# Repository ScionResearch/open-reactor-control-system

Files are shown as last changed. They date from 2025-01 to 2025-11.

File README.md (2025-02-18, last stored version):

# Open Reactor Control System

A unified control platform for bioreactor systems, featuring a dual microcontroller architecture for robust control and monitoring capabilities.

## Hardware Architecture

The system is built around two microcontrollers:

1. **System Controller (RP2040)**
   - Primary system controller
   - Handles user interface and high-level control
   - Based on the Raspberry Pi RP2040 microcontroller
   - USB connectivity for configuration and monitoring

2. **I/O Controller (SAMD51)**
   - Dedicated I/O processing
   - Real-time sensor monitoring and control
   - Based on the Microchip SAMD51 microcontroller
   - Provides reliable, deterministic I/O handling

## Project Structure

- `orc-sys-mcu/`: System Controller firmware (RP2040)
- `orc-io-mcu/`: I/O Controller firmware (SAMD51)
- `hardware/`: Hardware design files and documentation
  - Schematics
  - Pin assignments
  - PCB design files

## PCB Assembly

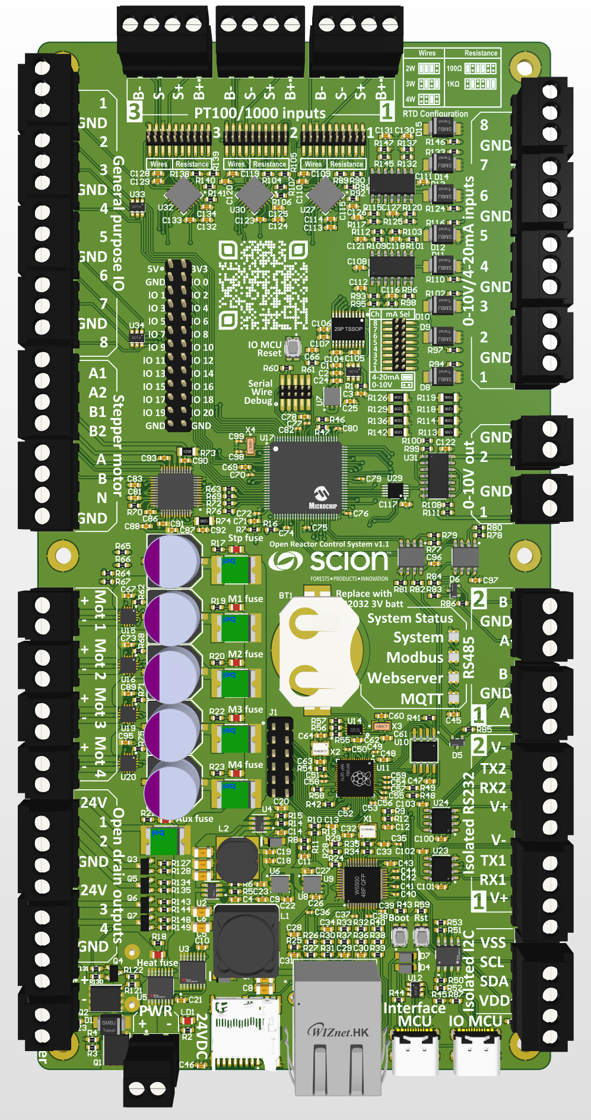
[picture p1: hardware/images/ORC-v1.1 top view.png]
PCB Top View

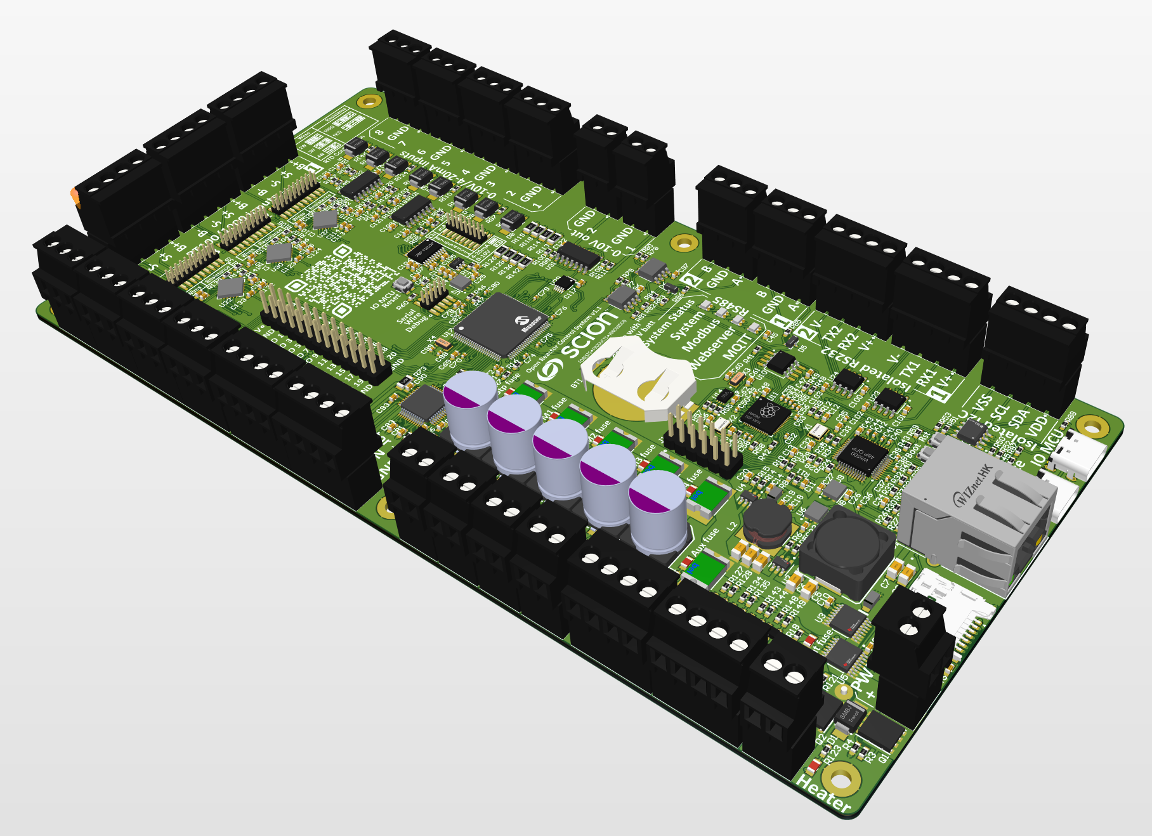
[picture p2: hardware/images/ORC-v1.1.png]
PCB Assembly


## Current Status

This project is currently under active development. The basic hardware and firmware architecture is established, with ongoing work to implement and refine the control and monitoring capabilities.

## Development

This is a PlatformIO-based project. Each microcontroller has its own PlatformIO project configuration and can be built and programmed independently.

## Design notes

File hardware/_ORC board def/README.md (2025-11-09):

# Scion ORC M4 Custom Board Definition

This directory contains the custom PlatformIO board definition for the Scion Open Reactor Controller M4 (ORC-IO-MCU).

## Board Specifications

- **MCU**: ATSAME51N20A (Cortex-M4)
- **Clock Speed**: 120 MHz
- **RAM**: 256 KB
- **Flash**: 1 MB (with bootloader offset)
- **USB VID/PID**: 0x04D8:0xEB60, 0x04D8:0xEB61

## Directory Structure

```
_ORC board def/
├── boards/
│   └── scion_orc_m4.json          # Board definition for PlatformIO
├── variants/
│   └── orc_m4/
│       ├── variant.h               # Pin definitions and mappings
│       ├── variant.cpp             # Pin configuration implementation
│       ├── pins_arduino.h          # Arduino-style pin mapping
│       └── linker_scripts/
│           └── gcc/
│               ├── flash_with_bootloader.ld     # Linker script with bootloader
│               └── flash_without_bootloader.ld  # Linker script without bootloader
└── bootloaders/
    └── orc_m4/
        ├── bootloader-orc_io_m4-v3.16.0-19-g4365018.bin
        └── update-bootloader-orc_io_m4-v3.16.0-19-g4365018.uf2
```

## PlatformIO Integration

### Automatic Setup (Already Configured)

The `orc-io-mcu/platformio.ini` is already configured to use this custom board definition:

```ini
[platformio]
boards_dir = ../hardware/_ORC board def/boards

[env:scion_orc_m4]
platform = atmelsam
board = scion_orc_m4
framework = arduino
board_build.variants_dir = ../hardware/_ORC board def/variants
lib_deps =
    khoih-prog/FlashStorage_SAMD@^1.3.2
```

**No additional setup is required** - PlatformIO will automatically find and use the custom board definition.

### How It Works

1. **`boards_dir`** - Tells PlatformIO where to find custom board JSON files
2. **`board`** - References the board name (matches `scion_orc_m4.json`)
3. **`board_build.variants_dir`** - Points to custom pin definitions and linker scripts

When you run `pio run`, PlatformIO will:
- Load the board configuration from `boards/scion_orc_m4.json`
- Use the variant files from `variants/orc_m4/` for pin mappings
- Apply the correct linker script (`flash_with_bootloader.ld`)
- Configure compiler flags for SAMD51 with FPU support

## Board Configuration Details

The `scion_orc_m4.json` file defines:

- **Build settings**: Cortex-M4 with FPU, SAMD51 core, 120MHz clock
- **Debug support**: J-Link, Atmel-ICE, OpenOCD configurations
- **Upload protocols**: SAM-BA (USB bootloader), J-Link, Atmel-ICE
- **Bootloader offset**: 0x4000 (16KB reserved for UF2 bootloader)

## Bootloader

The board uses a UF2 bootloader based on Adafruit's SAMD bootloader:

- **Version**: v3.16.0-19-g4365018
- **Offset**: 0x4000 (16KB)
- **Protocol**: SAM-BA over USB
- **Features**:
  - USB mass storage device (appears as "ORCM4BOOT")
  - 1200 baud touch to enter bootloader mode
  - Native USB support

### Installing/Updating Bootloader

To update the bootloader:

1. **Via UF2** (if bootloader already present):
   - Double-tap the reset button to enter bootloader mode
   - Drag `update-bootloader-orc_io_m4-v3.16.0-19-g4365018.uf2` to the USB drive

2. **Via J-Link/Atmel-ICE** (for initial programming):
   - Flash `bootloader-orc_io_m4-v3.16.0-19-g4365018.bin` at address 0x00000000

## Pin Definitions

Custom pin mappings are defined in `variants/orc_m4/`:

- Refer to `hardware/SAMD Pin Mux.xlsx` for complete pin assignments
- `variant.h` and `variant.cpp` define Arduino-style pin numbers
- Hardware peripherals (SPI, I2C, UART) are mapped to specific pins

## Troubleshooting

### Board not recognized

If PlatformIO doesn't recognize the board:
```bash
cd orc-io-mcu
pio run --target envdump
```

You should see: `PLATFORM: Atmel SAM > Scion Open Reactor Controller M4`

### Build fails

1. Ensure you're in the `orc-io-mcu` directory
2. Clean and rebuild:
   ```bash
   pio run --target clean
   pio run
   ```

### Upload fails

1. Check USB connection
2. Try entering bootloader mode manually (double-tap reset)
3. Verify the board appears as a USB device:
   ```bash
   ls /dev/ttyACM*
   ```

## Development

### Modifying Pin Definitions

1. Edit `variants/orc_m4/variant.h` and `variant.cpp`
2. Rebuild your project - PlatformIO will use the updated definitions

### Changing Bootloader Settings

1. Edit `boards/scion_orc_m4.json`
2. Modify `upload.offset_address` if changing bootloader size
3. Update linker script accordingly

## References

- [PlatformIO Custom Boards](https://docs.platformio.org/en/latest/platforms/creating_board.html)
- [Atmel SAM Platform](https://docs.platformio.org/en/latest/platforms/atmelsam.html)
- [ATSAME51N20A Datasheet](https://www.microchip.com/en-us/product/ATSAME51N20A)
- [Project Schematics](../Open%20Reactor%20Control%20System%20Schematics%20v1.2.pdf)

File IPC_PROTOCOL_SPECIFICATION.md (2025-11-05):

# Inter-Processor Communication (IPC) Protocol Specification
**Version:** 2.5  
**Date:** 2025-10-27  
**Status:** ✅ Implemented & Operational

---

## 1. OVERVIEW

### 1.1 Purpose
High-speed, robust binary communication protocol between:
- **SAME51N20A** (I/O Controller) - Sensors, actuators, peripherals
- **RP2040** (System Controller) - Network, MQTT, SD, RTC, web UI

### 1.2 Physical Interface
- **Medium:** UART (Serial1)
- **Pins (SAME51):** PIN_MI_TX (52), PIN_MI_RX (53)
- **Pins (RP2040):** PIN_SI_TX (16), PIN_SI_RX (17)
- **Trace Length:** ~80mm PCB trace
- **Baud Rate:** **2,000,000 bps (2 Mbps)** ⚡
  - Tested reliable up to 3 Mbps
  - 2 Mbps selected for robust operation
- **Configuration:** 8N1 (8 data bits, no parity, 1 stop bit)

### 1.3 Design Principles
- ✅ **Lightweight:** 8-byte overhead per packet
- ✅ **Robust:** CRC16-CCITT error detection
- ✅ **Scalable:** Extensible message types, 100-object index
- ✅ **Non-blocking:** Async state machine, TX queue
- ✅ **Fast:** 2 Mbps, minimal latency (<1ms per packet)
- ✅ **Type-safe:** Object type verification on all operations

---

## 2. PACKET STRUCTURE

### 2.1 Binary Frame Format

```
┌──────────┬──────────┬──────────┬──────────┬────────────┬──────────┐
│  START   │  LENGTH  │   MSG    │ PAYLOAD  │    CRC16   │   END    │
│  BYTE    │ (2 bytes)│   TYPE   │ (N bytes)│  (2 bytes) │   BYTE   │
├──────────┼──────────┼──────────┼──────────┼────────────┼──────────┤
│   0x7E   │  uint16  │  uint8   │  0-1024  │   uint16   │   0x7E   │
└──────────┴──────────┴──────────┴──────────┴────────────┴──────────┘

Total overhead: 8 bytes per packet
```

**Field Definitions:**
- **START (0x7E):** Frame delimiter (same for start and end)
- **LENGTH:** Payload size including MSG_TYPE (big-endian uint16)
- **MSG_TYPE:** Message identifier (uint8, see section 3)
- **PAYLOAD:** Variable data (0-1024 bytes max)
- **CRC16:** CRC16-CCITT of LENGTH + MSG_TYPE + PAYLOAD
- **END (0x7E):** Frame delimiter

### 2.2 Byte Stuffing
To prevent frame marker confusion in payload:
- **0x7E** in data → **0x7D 0x5E** (escape + XOR 0x20)
- **0x7D** in data → **0x7D 0x5D** (escape + XOR 0x20)

Applied to: LENGTH, MSG_TYPE, PAYLOAD, CRC fields

### 2.3 CRC16-CCITT
- **Polynomial:** 0x1021
- **Initial Value:** 0xFFFF
- **Coverage:** LENGTH (2) + MSG_TYPE (1) + PAYLOAD (N) bytes
- **Transmission:** Big-endian (MSB first)

---

## 3. MESSAGE TYPES

### 3.1 Message Type Enumeration

```cpp
enum IPC_MsgType : uint8_t {
    // Handshake & Status (0x00-0x0F)
    IPC_MSG_PING            = 0x00,  // Keepalive ping
    IPC_MSG_PONG            = 0x01,  // Ping response ✅ CRITICAL
    IPC_MSG_HELLO           = 0x02,  // Initial handshake
    IPC_MSG_HELLO_ACK       = 0x03,  // Handshake acknowledgment
    IPC_MSG_ERROR           = 0x04,  // Error notification
    
    // Object Index Management (0x10-0x1F)
    IPC_MSG_INDEX_SYNC_REQ  = 0x10,  // Request full index sync
    IPC_MSG_INDEX_SYNC_DATA = 0x11,  // Index sync data packet
    IPC_MSG_INDEX_ADD       = 0x12,  // Add object to index
    IPC_MSG_INDEX_REMOVE    = 0x13,  // Remove object from index
    IPC_MSG_INDEX_UPDATE    = 0x14,  // Update object metadata
    
    // Sensor Data (0x20-0x2F)
    IPC_MSG_SENSOR_READ_REQ      = 0x20,  // Request sensor reading
    IPC_MSG_SENSOR_DATA          = 0x21,  // Sensor data response
    IPC_MSG_SENSOR_STREAM        = 0x22,  // Continuous streaming
    IPC_MSG_SENSOR_BATCH         = 0x23,  // Batch sensor data
    IPC_MSG_SENSOR_BULK_READ_REQ = 0x24,  // ✅ Bulk read request (multiple sensors)
    
    // Control Data (0x30-0x3F)
    IPC_MSG_CONTROL_WRITE   = 0x30,  // Write setpoint/parameter
    IPC_MSG_CONTROL_ACK     = 0x31,  // Write acknowledgment
    IPC_MSG_CONTROL_READ    = 0x32,  // Read control parameters
    IPC_MSG_CONTROL_DATA    = 0x33,  // Control data response
    
    // Device Management (0x40-0x4F)
    IPC_MSG_DEVICE_CREATE   = 0x40,  // Create peripheral device
    IPC_MSG_DEVICE_DELETE   = 0x41,  // Delete peripheral device
    IPC_MSG_DEVICE_CONFIG   = 0x42,  // Configure device
    IPC_MSG_DEVICE_STATUS   = 0x43,  // Device status response
    
    // Fault & Message (0x50-0x5F)
    IPC_MSG_FAULT_NOTIFY    = 0x50,  // Fault notification
    IPC_MSG_MESSAGE_NOTIFY  = 0x51,  // General message
    IPC_MSG_FAULT_CLEAR     = 0x52,  // Clear fault
    
    // Configuration (0x60-0x6F)
    IPC_MSG_CONFIG_READ     = 0x60,  // Read configuration
    IPC_MSG_CONFIG_WRITE    = 0x61,  // Write configuration
    IPC_MSG_CONFIG_DATA     = 0x62,  // Configuration data
    IPC_MSG_CALIBRATE       = 0x63,  // Calibration command
};
```

### 3.2 Message Flow Examples

#### Startup Handshake
```
RP2040 → SAME51: IPC_MSG_HELLO (protocol v1.0.0, firmware v1.0.1)
SAME51 → RP2040: IPC_MSG_HELLO_ACK (firmware v1.0.0, 64 objects max)
RP2040 → SAME51: IPC_MSG_INDEX_SYNC_REQ
SAME51 → RP2040: IPC_MSG_INDEX_SYNC_DATA (entries 0-9)
SAME51 → RP2040: IPC_MSG_INDEX_SYNC_DATA (entries 10-19)
...
```

#### Keepalive (Every 1 Second)
```
SAME51 → RP2040: IPC_MSG_PING
RP2040 → SAME51: IPC_MSG_PONG
```
⚠️ **Connection timeout:** 3 missed PINGs (3 seconds)

---

## 4. PAYLOAD STRUCTURES

### 4.1 Handshake Messages

#### HELLO (0x02)
```cpp
struct IPC_Hello_t {
    uint32_t protocolVersion;  // e.g., 0x00010000 = v1.0.0
    uint32_t firmwareVersion;  // e.g., 0x00010001 = v1.0.1
    char deviceName[32];       // "SAME51-IO-MCU" or "RP2040-ORC-SYS"
} __attribute__((packed));
```

#### HELLO_ACK (0x03)
```cpp
struct IPC_HelloAck_t {
    uint32_t protocolVersion;
    uint32_t firmwareVersion;
    uint16_t maxObjectCount;      // SAME51: 64 (MAX_NUM_OBJECTS)
    uint16_t currentObjectCount;  // Currently registered objects
} __attribute__((packed));
```

### 4.2 Object Index Messages

#### INDEX_SYNC_DATA (0x11)
```cpp
struct IPC_IndexEntry_t {
    uint16_t index;           // 0-79
    uint8_t objectType;       // ObjectType enum
    uint8_t flags;            // Bit 0: valid, Bit 1: fixed
    char name[40];            // Null-terminated name
    char unit[8];             // Unit string (if applicable)
} __attribute__((packed));

struct IPC_IndexSync_t {
    uint16_t packetNum;       // Current packet (0-based)
    uint16_t totalPackets;    // Total packets in sync
    uint8_t entryCount;       // Entries in this packet
    IPC_IndexEntry_t entries[10];  // Up to 10 entries/packet
} __attribute__((packed));
```

### 4.3 Sensor Data Messages

#### SENSOR_DATA (0x21)
```cpp
struct IPC_SensorData_t {
    uint16_t index;          // Object index
    uint8_t objectType;      // Type verification
    uint8_t flags;           // Bit 0: fault, Bit 1: newMessage, Bit 2: running, Bit 3: direction
    float value;             // Primary sensor value
    char unit[8];            // Unit string (for primary value)
    uint32_t timestamp;      // Optional (0 if unused)
    char message[100];       // Optional message
    
    // Multi-value extension (v2.3+)
    uint8_t valueCount;      // Number of additional values (0 = only primary value)
    float additionalValues[4];     // Up to 4 additional values
    char additionalUnits[4][8];    // Units for each additional value
} __attribute__((packed));
```

**Multi-Value Support (v2.3):**
- Complex objects can now transmit multiple related values in a single message
- `valueCount = 0`: Traditional single-value mode (backward compatible)
- `valueCount > 0`: Additional values available in `additionalValues[]` array
- Each additional value has its own unit string in `additionalUnits[]`

**Example Use Cases:**
- **DC Motors:** Primary = power (%), Additional[0] = current (A)
- **Energy Monitors:** Primary = voltage (V), Additional[0] = current (A), Additional[1] = power (W)
- **Hamilton Probes:** Primary = pH/DO, Additional[0] = temperature (°C)
- **Stepper Motor:** Primary = RPM, Additional[0] = current (A)

**Benefits:**
- Single IPC message instead of multiple sensor objects
- Atomically consistent (all values from same measurement cycle)
- More efficient use of object index space
- Reduced IPC traffic

#### SENSOR_BULK_READ_REQ (0x24) ✅ NEW
**Purpose:** Request multiple sensor readings in one operation

```cpp
struct IPC_SensorBulkReadReq_t {
    uint16_t startIndex;     // Starting object index (e.g., 0)
    uint16_t count;          // Number of objects to read (e.g., 21)
} __attribute__((packed));
```

**Response:** Multiple `IPC_MSG_SENSOR_DATA` (0x21) packets sent sequentially

**Example Flow:**
```
RP2040 → SAME51: SENSOR_BULK_READ_REQ (startIndex=0, count=31)
SAME51 → RP2040: SENSOR_DATA (index=0, ADC 1)
SAME51 → RP2040: SENSOR_DATA (index=1, ADC 2)
...
SAME51 → RP2040: SENSOR_DATA (index=20, GPIO 8)
SAME51 → RP2040: SENSOR_DATA (index=21, Digital Output 1)
...
SAME51 → RP2040: SENSOR_DATA (index=30, DC Motor 4)
```

**TX Queue Management:** 
- IO MCU TX queue limited to 8 packets
- Handler actively drains queue by calling `ipc_processTxQueue()` between sends
- Waits for queue space before sending each response (prevents overflow)
- Typical performance: 31 objects read in ~30-40ms

**Benefits:**
- Single 4-byte request vs 31 individual requests (96% reduction)
- Prevents RX buffer overflow on SYS MCU
- Efficient bulk object polling for cache updates
- Used by background polling: 31 objects (sensors + outputs) updated every 1 second
- Provides real-time output status (running state, power, current, etc.)

### 4.4 Control Messages 🚧 IN PROGRESS

#### CONTROL_WRITE (0x30) - Digital Output Control
**Purpose:** Control digital outputs (on/off, PWM duty cycle)

```cpp
struct IPC_DigitalOutputControl_t {
    uint16_t index;          // Output index (21-25)
    uint8_t objectType;      // Type verification (OBJ_T_DIGITAL_OUTPUT)
    uint8_t command;         // Command type (see below)
    bool state;              // Output state (true=on, false=off)
    float pwmDuty;           // PWM duty cycle (0-100%)
    uint8_t reserved[3];     // Padding for alignment
} __attribute__((packed));
```

**Command Types:**
```cpp
enum DigitalOutputCommand : uint8_t {
    DOUT_CMD_SET_STATE = 0x01,   // Set on/off state
    DOUT_CMD_SET_PWM   = 0x02,   // Set PWM duty cycle
    DOUT_CMD_DISABLE   = 0x03,   // Disable output
};
```

#### CONTROL_WRITE (0x30) - Stepper Motor Control
**Purpose:** Control stepper motor parameters and motion

```cpp
struct IPC_StepperControl_t {
    uint16_t index;          // Stepper index (26)
    uint8_t objectType;      // Type verification (OBJ_T_STEPPER_MOTOR)
    uint8_t command;         // Command type (see below)
    float rpm;               // Target RPM
    bool direction;          // true=forward, false=reverse
    bool enable;             // Enable motor
    uint8_t reserved[2];     // Padding
} __attribute__((packed));
```

**Command Types:**
```cpp
enum StepperCommand : uint8_t {
    STEPPER_CMD_SET_RPM   = 0x01,  // Set target RPM
    STEPPER_CMD_SET_DIR   = 0x02,  // Set direction
    STEPPER_CMD_START     = 0x03,  // Start motor
    STEPPER_CMD_STOP      = 0x04,  // Stop motor
    STEPPER_CMD_UPDATE    = 0x05,  // Update RPM while running
};
```

#### CONTROL_WRITE (0x30) - DC Motor Control
**Purpose:** Control DC motor power and direction

```cpp
struct IPC_DCMotorControl_t {
    uint16_t index;          // Motor index (27-30)
    uint8_t objectType;      // Type verification (OBJ_T_BDC_MOTOR)
    uint8_t command;         // Command type (see below)
    float power;             // Power percentage (0-100%)
    bool direction;          // true=forward, false=reverse
    bool enable;             // Enable motor
    uint8_t reserved[2];     // Padding
} __attribute__((packed));
```

**Command Types:**
```cpp
enum DCMotorCommand : uint8_t {
    DCMOTOR_CMD_SET_POWER = 0x01,  // Set power percentage
    DCMOTOR_CMD_SET_DIR   = 0x02,  // Set direction
    DCMOTOR_CMD_START     = 0x03,  // Start motor
    DCMOTOR_CMD_STOP      = 0x04,  // Stop motor
    DCMOTOR_CMD_UPDATE    = 0x05,  // Update power while running
};
```

#### CONTROL_ACK (0x31) - Command Acknowledgment
**Purpose:** Acknowledge control command success/failure

```cpp
struct IPC_ControlAck_t {
    uint16_t index;          // Object index
    uint8_t objectType;      // Object type
    uint8_t command;         // Command that was executed
    bool success;            // true=success, false=failure
    uint8_t errorCode;       // Error code if success=false
    char message[100];       // Status/error message
} __attribute__((packed));
```

**Error Codes:**
```cpp
enum ControlErrorCode : uint8_t {
    CTRL_ERR_NONE           = 0x00,  // No error
    CTRL_ERR_INVALID_INDEX  = 0x01,  // Invalid object index
    CTRL_ERR_TYPE_MISMATCH  = 0x02,  // Object type mismatch
    CTRL_ERR_INVALID_CMD    = 0x03,  // Invalid command
    CTRL_ERR_OUT_OF_RANGE   = 0x04,  // Parameter out of range
    CTRL_ERR_NOT_ENABLED    = 0x05,  // Device not enabled
    CTRL_ERR_DRIVER_FAULT   = 0x06,  // Hardware driver fault
    CTRL_ERR_TIMEOUT        = 0x07,  // Command timeout
};
```

### 4.5 Configuration Messages ✅ IMPLEMENTED

#### CONFIG_ANALOG_INPUT (ADC Configuration)
```cpp
struct IPC_ConfigAnalogInput_t {
    uint8_t index;           // ADC index (0-7)
    char unit[8];            // Unit string (e.g., "mV", "V", "mA")
    float calScale;          // Calibration scale factor
    float calOffset;         // Calibration offset
} __attribute__((packed));
```

#### CONFIG_RTD (Temperature Sensor Configuration)
```cpp
struct IPC_ConfigRTD_t {
    uint8_t index;           // RTD index (10-12)
    char unit[8];            // Unit string (e.g., "C", "degC")
    uint8_t sensorType;      // 0=PT100, 1=PT1000
    uint8_t wireMode;        // 2=2-wire, 3=3-wire, 4=4-wire
    float calScale;          // Calibration scale factor
    float calOffset;         // Calibration offset
} __attribute__((packed));
```

**Configuration Flow:**
```
RP2040 → SAME51: CONFIG_ANALOG_INPUT (index=0, unit="V", scale=1.0, offset=0.0)
SAME51: Updates ADC configuration in real-time
```

---

## 5. OBJECT INDEX SYSTEM

### 5.1 Index Organization (80 Objects Total)

The object index provides a unified addressing scheme for all sensors, actuators, and control loops accessible via IPC.

**Fixed Indices (0-59):** Onboard SAME51 hardware & control objects

#### **Analog I/O (0-9)**
- **0-7:** Analog Inputs (ADC channels 1-8) - MCP3464
- **8-9:** Analog Outputs (DAC channels 1-2) - MCP48FEB

#### **Temperature Sensors (10-12)**
- **10-12:** RTD Temperature Sensors (PT100/PT1000 1-3) - MAX31865

#### **Digital I/O (13-20)**
- **13-20:** Digital GPIO (8 channels) - General purpose I/O

#### **Digital Outputs (21-25)**
- **21-24:** Digital Outputs (4 channels) - Open-drain, PWM capable
- **25:** Heater Output (1 channel) - High current, 1Hz PWM

#### **Motion Control (26-30)**
- **26:** Stepper Motor - TMC5130 driver
- **27-30:** DC Motors (4 channels) - DRV8235 drivers

#### **Energy Monitoring (31-32)**
- **31:** Main Power Monitor - INA260 sensor 1 (voltage V, current A, power W)
- **32:** Heater Power Monitor - INA260 sensor 2 (voltage V, current A, power W)

#### **Communication Ports (33-36)**
- **33:** Modbus Port 1 (RS-232) - Serial2
- **34:** Modbus Port 2 (RS-232) - Serial3
- **35:** Modbus Port 3 (RS-485) - Serial4
- **36:** Modbus Port 4 (RS-485) - Serial5

#### **Onboard Device Feedback (37-39)** 🚧 Reserved
- **37-39:** Reserved for additional onboard device status/feedback

#### **Controller Objects (40-49)** **WIP**
- **40-42:** Temperature Control (3 loops) - PID controllers
- **43:** pH Control - Dosing control
- **44-47:** Feed/waste Control - pumps
- **48:** Dissolved Oxygen Control - Gas mixing + stirrer
- **49:** Reserved

**Device Control Objects (50-69):** Peripheral device control
- Control interface for dynamic devices (setpoints, commands, status)
- Each device gets one control object (MFC setpoint, pump speed, etc.)
- Linked to sensor objects via `startSensorIndex` field
- **20 slots available** for device control

**Device Sensor Objects (70-99):** User-created peripheral sensors
- Sensor readings from dynamic devices (pH, DO, OD, flow, pressure, etc.)
- User-created via `IPC_MSG_DEVICE_CREATE`
- Assigned sequentially starting at 70, recycled on deletion
- Each device can have 1-4 sensors (e.g., MFC: flow + pressure)
- **30 slots available** for device sensors

### 5.2 Object Type Mapping

Each index has an associated `ObjectType` from the enum:

```cpp
// Sensors
OBJ_T_ANALOG_INPUT              // Indices 0-7
OBJ_T_ANALOG_OUTPUT             // Indices 8-9
OBJ_T_TEMPERATURE_SENSOR        // Indices 10-12, 60+
OBJ_T_DIGITAL_INPUT             // Indices 13-20
OBJ_T_DIGITAL_OUTPUT            // Indices 21-25
OBJ_T_ENERGY_SENSOR             // Indices 31-32 (multi-value: V, A, W)
OBJ_T_VOLTAGE_SENSOR            // Reserved for future use
OBJ_T_CURRENT_SENSOR            // Reserved for future use
OBJ_T_POWER_SENSOR              // Reserved for future use

// Motion
OBJ_T_STEPPER_MOTOR             // Index 26
OBJ_T_BDC_MOTOR                 // Indices 27-30

// Communication
OBJ_T_SERIAL_RS232_PORT         // Indices 33-34
OBJ_T_SERIAL_RS485_PORT         // Indices 35-36

// Controllers (40-49) - Future
OBJ_T_TEMPERATURE_CONTROL       // Indices 40-42
OBJ_T_PH_CONTROL                // Index 43
OBJ_T_DISSOLVED_OXYGEN_CONTROL  // Index 44
OBJ_T_OPTICAL_DENSITY_CONTROL   // Index 45
OBJ_T_GAS_FLOW_CONTROL          // Indices 46-47
OBJ_T_PUMP_CONTROL              // Index 48
OBJ_T_FEED_WASTE_CONTROL        // Index 49

// Device Controls (50-69) - ✅ Active
OBJ_T_DEVICE_CONTROL            // Control/status for peripheral devices

// Device Sensors (70-99) - ✅ Active
OBJ_T_PH_SENSOR                 // Indices 70+ (dynamic)
OBJ_T_DISSOLVED_OXYGEN_SENSOR   // Indices 70+ (dynamic)
OBJ_T_OPTICAL_DENSITY_SENSOR    // Indices 70+ (dynamic)
OBJ_T_FLOW_SENSOR               // Indices 70+ (dynamic)
OBJ_T_PRESSURE_SENSOR           // Indices 70+ (dynamic)
OBJ_T_TEMPERATURE_SENSOR        // Indices 10-12, 70+ (dynamic)
```

### 5.3 Unit Strings

Standard unit strings for sensor data:

| Object Type | Primary Unit | Notes |
|---|---|---|
| Analog Input | `mV` | Millivolts (configurable) |
| Analog Output | `mV` | Millivolts (0-10240 mV) |
| Temperature | `°C` | Celsius (configurable to °F/K) |
| Digital I/O | ` ` | Empty (boolean state) |
| Digital Output | ` ` | Empty (boolean state) |
| Energy Monitor | `V` | Primary: Volts, Additional: A, W |
| Stepper Motor | `rpm` | Revolutions per minute |
| DC Motor | `%` | Power percentage |
| Modbus Port | ` ` | Empty (status/config) |
| pH Sensor | `pH` | pH units (0-14) |
| DO Sensor | `mg/L` or `%` | Dissolved oxygen |
| OD Sensor | `OD` or `AU` | Optical density |
| Flow Sensor | `SLPM` | Standard liters per minute |
| Pressure Sensor | `kPa` or `bar` | Pressure units |

### 5.4 Type Safety
Every command includes `objectType` field:
- Prevents wrong commands to wrong device types
- Mismatch → `IPC_MSG_ERROR` with code `IPC_ERR_TYPE_MISMATCH`
- Validated on both SAME51 and RP2040 sides

### 5.5 Dual-Index Device Model ✅ **NEW v2.5**

Peripheral devices (MFCs, pH probes, pumps) use a **dual-index architecture** separating control from sensors:

#### **Control Object (50-69)**
- **Purpose:** Device setpoints, commands, status
- **One per device:** Single control point for the device
- **Contains:**
  - `setpoint` - Target value (flow rate, pH, etc.)
  - `actualValue` - Feedback from primary sensor
  - `connected` - Modbus/I2C connection status
  - `fault` - Fault condition flag
  - `message` - Status/error messages
  - `startSensorIndex` - Link to sensor objects (70-99)
  - `sensorCount` - Number of associated sensors

#### **Sensor Objects (70-99)**
- **Purpose:** Real-time sensor readings
- **1-4 per device:** Flow, pressure, temperature, etc.
- **Polled continuously:** Included in bulk read (indices 0-99)
- **Standard sensor format:** Value, unit, type, fault flags

#### **Example: Alicat MFC**
```
Index 50: Device Control
  - Setpoint: 100.0 SLPM
  - Actual: 99.8 SLPM (from sensor 70)
  - Connected: true
  - Fault: false
  
Index 70: Flow Sensor (OBJ_T_FLOW_SENSOR)
  - Value: 99.8
  - Unit: "SLPM"
  - Type: FLOW_SENSOR
  
Index 71: Pressure Sensor (OBJ_T_PRESSURE_SENSOR)
  - Value: 25.3
  - Unit: "PSI"
  - Type: PRESSURE_SENSOR
```

#### **Benefits:**
- ✅ **Clean separation:** Control (write) vs sensors (read)
- ✅ **Efficient polling:** Sensors in bulk read, control on-demand
- ✅ **Scalable:** 20 devices with up to 30 total sensors
- ✅ **Consistent API:** Control via `/api/device/{index}`, sensors via `/api/inputs`

---

## 6. DRIVER ARCHITECTURE

### 6.1 SAME51 Implementation

**Files:**
- `src/drivers/ipc/drv_ipc.h` - Driver structure and API
- `src/drivers/ipc/drv_ipc.cpp` - State machine, TX/RX
- `src/drivers/ipc/ipc_protocol.h` - Protocol definitions
- `src/drivers/ipc/ipc_handlers.cpp` - Message handlers

**State Machine:**
```
IDLE → Check for RX bytes, process TX queue
  ↓ (START byte detected)
RECEIVING → Accumulate bytes, unstuff, detect END
  ↓ (END byte detected)
PROCESSING → Validate CRC, dispatch to handler
  ↓
IDLE (or ERROR on failure)
```

**Key Functions:**
```cpp
bool ipc_init(void);
void ipc_update(void);  // Non-blocking, called @ 5ms
bool ipc_sendPacket(uint8_t msgType, const uint8_t *payload, uint16_t len);
bool ipc_sendPing(void);
bool ipc_sendPong(void);
bool ipc_sendHello(void);
bool ipc_isConnected(void);
```

### 6.2 RP2040 Implementation

**Files:**
- `lib/IPCprotocol/IPCProtocol.h` - Protocol class
- `lib/IPCprotocol/IPCProtocol.cpp` - Implementation
- `lib/IPCprotocol/IPCDataStructs.h` - Message structures
- `src/utils/ipcManager.cpp` - Integration layer

**Key Functions:**
```cpp
void begin(uint32_t baudRate = 2000000);
void update(void);  // Non-blocking
bool sendPacket(uint8_t messageType, const uint8_t *payload, uint16_t length);
bool sendPing(void);
bool sendHello(uint32_t protocol, uint32_t firmware, const char* name);
void registerHandler(uint8_t messageType, MessageCallback callback);
```

---

## 7. PERFORMANCE CHARACTERISTICS

### 7.1 Timing @ 2 Mbps
- **Bit time:** 0.5 µs
- **Byte time:** 5 µs (8 data + start + stop bits)
- **100-byte packet:** ~0.5 ms transmission
- **1024-byte packet:** ~5.1 ms transmission

### 7.2 CPU Usage
- **SAME51 IPC task (5ms):** <0.5% CPU
- **RP2040 IPC update:** <0.5% CPU
- **Packet processing:** 50-100 µs per packet

### 7.3 Throughput
- **Theoretical max:** ~200 KB/s (2 Mbps / 10 bits per byte)
- **Practical max:** ~150 KB/s (accounting for overhead)
- **Typical load:** <10 KB/s (sensor data + control)

---

## 8. ERROR HANDLING

### 8.1 Error Codes
```cpp
enum IPC_ErrorCode : uint8_t {
    IPC_ERR_CRC_FAIL       = 0x01,  // CRC validation failed
    IPC_ERR_INVALID_MSG    = 0x02,  // Unknown message type
    IPC_ERR_BUFFER_FULL    = 0x03,  // RX buffer overflow
    IPC_ERR_TIMEOUT        = 0x04,  // Packet timeout
    IPC_ERR_TYPE_MISMATCH  = 0x05,  // Object type mismatch
    IPC_ERR_INDEX_INVALID  = 0x06,  // Invalid object index
    IPC_ERR_QUEUE_FULL     = 0x07,  // TX queue full
    IPC_ERR_NOT_IMPLEMENTED= 0x08,  // Feature not implemented
    IPC_ERR_PARSE_FAIL     = 0x09,  // Payload parse error
};
```

### 8.2 Recovery Strategies
- **CRC error:** Discard packet, log error, continue
- **Buffer overflow:** Clear buffer, resync
- **Connection timeout:** Clear connected flag, await reconnect
- **Type mismatch:** Send error response, reject command

### 8.3 Keepalive System
- SAME51 sends PING every 1000 ms (`IPC_KEEPALIVE_MS`)
- RP2040 responds with PONG
- **Both sides** update `lastActivity` on:
  - Any successful RX packet
  - Any successful TX packet
- Connection timeout: 3000 ms (3 x keepalive interval)
- **Critical:** PONG handler must be implemented on both sides

---

## 9. IMPLEMENTATION STATUS

### 9.1 ✅ Completed Features
- [x] Binary packet framing with byte stuffing
- [x] CRC16-CCITT validation
- [x] State machine RX/TX processing
- [x] TX queue (8 packets deep) with active draining
- [x] PING/PONG keepalive with timeout
- [x] HELLO handshake with version checking
- [x] Message handler registration
- [x] Error detection and reporting
- [x] Non-blocking operation
- [x] 2 Mbps reliable communication
- [x] **Bulk sensor read (SENSOR_BULK_READ_REQ)**
- [x] **Background sensor polling (1 Hz cache updates)**
- [x] **Object cache system on SYS MCU**

### 9.2 🚧 In Progress
- [x] **Output control commands (CONTROL_WRITE, CONTROL_ACK)**
  - [x] Digital outputs (on/off, PWM)
  - [x] Stepper motor (RPM, direction, start/stop)
  - [x] DC motors (power, direction, start/stop)
- [x] **Extend bulk read to include outputs (indices 0-30)**
  - [x] Updated polling from 21 to 31 objects
  - [x] Increased UART FIFO buffer to 8192 bytes
- [ ] **Output configuration persistence on SYS MCU**
- [ ] **Output control command senders on SYS MCU**
- [ ] **Web API endpoints for output control**
- [ ] Object index synchronization (partial - fixed objects working)
- [ ] Device management (create/delete)
- [ ] Calibration protocol

### 9.3 📋 Planned Features
- [ ] Sensor batch messages (multiple sensors per packet)
- [ ] Automatic reconnection with state rebuild
- [ ] REST API for device management
- [ ] MQTT integration for sensor & output data
- [ ] Control loop objects (PID, sequencers)

---

## 10. TESTING & VALIDATION

### 10.1 Protocol Tests
- ✅ PING/PONG exchange
- ✅ HELLO handshake
- ✅ CRC validation (intentional corruption)
- ✅ Byte stuffing (0x7E, 0x7D in payload)
- ✅ Connection timeout detection
- ✅ TX/RX packet counting
- ✅ Baud rate up to 3 Mbps

### 10.2 Test Commands (RP2040 Terminal)
```
ping        - Send PING, wait for PONG
hello       - Send HELLO, initiate handshake
ipc-stats   - Display TX/RX counters, errors
```

---

## 11. CONFIGURATION

### 11.1 Compile-Time Configuration

**SAME51** (`ipc_protocol.h`):
```cpp
#define IPC_PROTOCOL_VERSION    0x00010000  // v1.0.0
#define IPC_TX_QUEUE_SIZE       8           // TX queue depth
#define IPC_KEEPALIVE_MS        1000        // Keepalive interval
#define IPC_DEBUG_ENABLED       0           // Debug output (0=off, 1=on)
#define MAX_NUM_OBJECTS         64          // Max object index
```

**RP2040** (`IPCDataStructs.h`):
```cpp
#define IPC_PROTOCOL_VERSION    0x00010000
#define IPC_TX_QUEUE_SIZE       8
#define IPC_MAX_PAYLOAD_SIZE    1024
#define IPC_MAX_HANDLERS        32
#define IPC_DEBUG_ENABLED       0
```

### 11.2 Baud Rate Configuration

**SAME51** (`drv_ipc.cpp`):
```cpp
ipcDriver.uart->begin(2000000);  // 2 Mbps
```

**RP2040** (`ipcManager.cpp`):
```cpp
ipc.begin(2000000);  // 2 Mbps
```

---

## 12. FUTURE ENHANCEMENTS

### 12.1 Protocol Extensions
- **Message priorities:** Separate queues for critical vs normal
- **Flow control:** Handshake to prevent overflow
- **Compression:** Optional payload compression for large data
- **Encryption:** Optional AES for sensitive data

### 12.2 Feature Additions
- **Streaming mode:** Continuous sensor data without requests
- **Batch operations:** Multiple commands in single packet
- **Firmware updates:** OTA update protocol over IPC
- **Diagnostics:** Built-in protocol analyzer/sniffer

---

## 13. TROUBLESHOOTING

### 13.1 Common Issues

**No communication:**
- Check UART pins (TX/RX crossed between MCUs)
- Verify baud rate matches (2 Mbps on both sides)
- Check ground connection
- Verify Serial1 on correct pins

**Connection timeout:**
- Check PONG handler is registered on both sides
- Verify keepalive is enabled (not disabled for debugging)
- Check `lastActivity` updates on RX/TX

**CRC errors:**
- Check for noise on UART lines
- Verify CRC polynomial matches (0x1021)
- Check byte stuffing implementation
- Try lower baud rate

**Missing messages:**
- Check TX queue size (may be full)
- Verify handler is registered for message type
- Check message type value matches enum
- Enable debug output (`IPC_DEBUG_ENABLED = 1`)

---

## 14. REFERENCES

### 14.1 Related Documents
- `HELLO_HANDSHAKE_IMPLEMENTED.md` - Handshake implementation guide
- `IPC_CLEANUP_COMPLETE.md` - Debug output cleanup
- `PROJECT_OVERVIEW.md` - System architecture

### 14.2 Standards
- **CRC16-CCITT:** ITU-T Recommendation V.41
- **UART:** RS-232 compatible (8N1)

---

**Document Version:** 2.4  
**Protocol Version:** v1.0.0  
**Last Updated:** 2025-10-25  
**Status:** ✅ Operational at 2 Mbps with multi-value sensor data + output control  
**Maintainer:** Open Reactor Control System Team

**Recent Updates (v2.4):**
- Consolidated power sensors from 6 objects to 2 energy monitors (indices 31-32)
- Added `OBJ_T_ENERGY_SENSOR` type with multi-value support (voltage, current, power)
- Shifted COM ports from indices 37-40 to 33-36
- Reserved indices 37-40 for future expansion
- Deprecated individual voltage/current/power sensor types (kept for future use)

**Previous Updates (v2.3):**
- Added multi-value sensor data extension to `IPC_SensorData_t`
- Implemented `valueCount`, `additionalValues[]`, and `additionalUnits[]` fields
- DC motors now transmit power (%) + current (A) in single message
- Backward compatible with single-value objects
- Fixed DRV8235 library bug (static buffer sharing across motor instances)

**Previous Updates (v2.2):**
- Added CONTROL_WRITE (0x30) message structures for outputs
- Added CONTROL_ACK (0x31) acknowledgment structure
- Defined control commands for digital outputs, stepper motor, DC motors
- Added error codes for control command failures
- Updated implementation status for output control feature

**Previous Updates (v2.1):**
- Added SENSOR_BULK_READ_REQ message type (0x24)
- Implemented TX queue draining to handle bulk responses
- Added background sensor polling architecture
- Documented object cache system on SYS MCU

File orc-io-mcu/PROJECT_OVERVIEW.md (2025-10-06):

# Open Reactor Control System - IO MCU
## Project Overview & Architecture Documentation

**Last Updated:** 2025-10-05 16:35

**Recent Changes:**
- **NEW:** Designed comprehensive IPC (Inter-Processor Communication) protocol for SAME51↔RP2040 communication
- Reorganized drivers into `onboard/` and `peripheral/` subdirectories
- Converted peripheral drivers to class-based architecture for multiple instance support
- Added Hamilton Arc common definitions with unit code lookup table (32 unit types)
- Implemented automatic unit reading for Hamilton Arc sensors
- Added HamiltonArcDO driver for dissolved oxygen sensors
- Added HamiltonArcOD driver for optical density sensors
- Expanded sensor unit fields from 5 to 8 characters to accommodate longer unit names

## 1. PROJECT PURPOSE

This is the firmware for the IO MCU (Input/Output Microcontroller Unit) of an Open Reactor Control System (ORC). It's designed to interface with and manage various sensors, outputs, and communication protocols for a bioreactor or similar laboratory equipment.

## 2. HARDWARE PLATFORM

- **MCU:** ATSAME51N20A (ARM Cortex-M4)
  - Custom board: `scion_orc_m4`
  - 120MHz clock speed
  - Framework: Arduino for SAMD
- **Platform:** atmelsam (PlatformIO)
- **Key External Library:** FlashStorage_SAMD@^1.3.2 for EEPROM emulation

## 3. SYSTEM ARCHITECTURE

### 3.1 Core Design Pattern
The system follows a **driver-based, object-oriented architecture** with:
- Centralized initialization in `sys_init.h/cpp`
- Modular drivers for each hardware peripheral
- Task-based scheduling for periodic operations
- Object index system for dynamic sensor/output management
- Calibration support for analog I/O

### 3.2 File Structure
```
orc-io-mcu/
├── lib/                         # Custom libraries
│   ├── Scheduler/              # Custom task scheduler with CPU monitoring
│   ├── modbus-rtu-master/      # Custom non-blocking Modbus RTU master
│   ├── MCP3464/                # 8-channel ADC driver
│   ├── MCP48FEB/               # 2-channel DAC driver
│   ├── MAX31865/               # RTD temperature sensor driver
│   ├── TMC5130/                # Stepper motor driver
│   ├── DRV8235/                # DC motor driver
│   └── INA260/                 # Power sensor driver
├── src/
│   ├── drivers/                # Hardware abstraction drivers
│   │   ├── objects.h/cpp      # Object type definitions & index
│   │   ├── onboard/           # Fixed onboard device drivers
│   │   │   ├── drv_adc.*          # Analog input driver (8 channels)
│   │   │   ├── drv_dac.*          # Analog output driver (2 channels)
│   │   │   ├── drv_rtd.*          # RTD temperature sensors (3x MAX31865)
│   │   │   ├── drv_gpio.*         # GPIO (8 main + 15 expansion)
│   │   │   ├── drv_output.*       # Digital outputs (4 + 1 heater)
│   │   │   ├── drv_modbus.*       # Modbus base driver (4 ports)
│   │   │   ├── drv_stepper.*      # TMC5130 stepper driver
│   │   │   ├── drv_bdc_motor.*    # DRV8235 motor driver (4x)
│   │   │   └── drv_pwr_sensor.*   # INA260 power sensors (2x)
│   │   ├── peripheral/        # External device class-based drivers
│   │   │   ├── drv_modbus_hamilton_arc_common.h  # Hamilton Arc common definitions
│   │   │   ├── drv_modbus_hamilton_ph.*          # Hamilton pH probe (class)
│   │   │   ├── drv_modbus_hamilton_arc_do.*      # Hamilton Arc DO sensor (class)
│   │   │   ├── drv_modbus_hamilton_arc_od.*      # Hamilton Arc OD sensor (class)
│   │   │   └── drv_modbus_alicat_mfc.*           # Alicat MFC (class)
│   │   └── ipc/               # Inter-processor communication
│   │       ├── ipc_protocol.h     # Protocol definitions & structs
│   │       ├── drv_ipc.h          # IPC driver header
│   │       ├── drv_ipc.cpp        # Core driver implementation
│   │       └── ipc_handlers.cpp   # Message handler implementations
│   ├── hardware/
│   │   └── pins.h             # Pin definitions (77 pins defined)
│   ├── tasks/
│   │   └── taskManager.*      # Task instances and scheduler
│   ├── utility/
│   │   └── calibrate.*        # Calibration data management
│   ├── sys_init.h             # System-wide includes
│   └── main.cpp               # Main program
├── IPC_PROTOCOL_PLAN.md       # IPC protocol specification
└── platformio.ini             # Build configuration
```

## 4. OBJECT SYSTEM

### 4.1 Object Types (40+ possible objects)
Defined in `objects.h`, the system supports heterogeneous objects via tagged unions:

**Sensors:**
- AnalogInput_t (8x) - Voltage/current inputs
- DigitalIO_t (8 + 15 expansion)
- TemperatureSensor_t (3x RTD)
- PhSensor_t, DissolvedOxygenSensor_t, OpticalDensitySensor_t
- FlowSensor_t, PressureSensor_t
- PowerSensor_t (2x INA260)

**Outputs:**
- AnalogOutput_t (2x DAC)
- DigitalOutput_t (4 + 1 heater with PWM support)

**Actuators:**
- StepperDevice_t (1x TMC5130)
- MotorDevice_t (4x DRV8235)

**Control Objects:**
- TemperatureControl_t, PhControl_t, DissolvedOxygenControl_t
- gasFlowControl_t, stirrerControl_t, pumpControl_t
- feedControl_t, wasteControl_t

### 4.2 Object Index System
- Global array: `objIndex[MAX_NUM_OBJECTS]` (80 max)
- Each entry contains: type tag, void pointer, name string, valid flag
- Allows dynamic runtime enumeration of all system objects
- Used for communication with main control MCU

### 4.3 Calibration System
- Each analog I/O has a `Calibrate_t` object with scale/offset
- 20-entry calibration table stored in emulated EEPROM (FlashStorage_SAMD)
- Two-point calibration support: `calibrate_calc(expected_1, expected_2, actual_1, actual_2)`
- Version control to force re-initialization when structure changes

## 5. TASK SCHEDULING SYSTEM

### 5.1 Custom Scheduler Library
Located in `lib/Scheduler/`, provides:
- **Non-blocking execution** with millisecond precision
- **Priority support** (high-priority tasks run first)
- **Repeat/one-shot modes**
- **CPU usage tracking** per task (10-second rolling window)
- **Performance statistics** (min/max/avg execution time)

### 5.2 Active Tasks (from main.cpp)
```cpp
analog_input_task    → ADC_update()              @ 10ms   (high priority)
output_task          → output_update()           @ 100ms
gpio_task            → gpio_update()             @ 100ms  (high priority)
modbus_task          → modbus_manage()           @ 10ms   (high priority)
ipc_task             → ipc_update()              @ 5ms    (high priority)
phProbe_task         → modbusHamiltonPH_manage() @ 2000ms
mfc_task             → modbusAlicatMFC_manage()  @ 2000ms
RTDsensor_task       → RTD_manage()              @ 200ms
printStuff_task      → printStuff()              @ 1000ms
SchedulerAlive_task  → schedulerHeatbeat()       @ 1000ms
TEST_TASK            → testTaskFunction()        @ 5000ms
```

High-priority tasks are executed first in each scheduler cycle.

## 6. DRIVER DETAILS

### 6.1 Analog Input (ADC) Driver
- **IC:** MCP3464 (24-bit, 8-channel ADC)
- **Communication:** SPI
- **Features:**
  - Continuous scan mode (all 8 channels)
  - Voltage divider ratio: 5.024x
  - Configurable units: mV (default), V, mA, µV
  - Per-channel calibration support
  - 314µV per LSB base resolution
- **Current Mappings (from main.cpp):**
  - Ch 1-2: V mode
  - Ch 3-4: mA mode (240Ω current sensing resistor)
  - Ch 5-6: µV mode
  - Ch 7-8: Default (mV)

### 6.2 Analog Output (DAC) Driver
- **IC:** MCP48FEB (12-bit, 2-channel DAC)
- **Communication:** SPI
- **Features:**
  - 0-10.24V output range (with 5x op-amp gain)
  - 2.048V internal reference
  - 2.50mV per LSB
  - Per-channel calibration
  - Settings saved to IC's EEPROM

### 6.3 RTD Temperature Sensors
- **IC:** MAX31865 (3 instances)
- **Communication:** SPI (individual CS pins)
- **Features:**
  - PT100 or PT1000 sensor support
  - 2-wire, 3-wire, or 4-wire configuration
  - Auto-conversion mode
  - Comprehensive fault detection
  - Per-sensor calibration

### 6.4 Digital Outputs
- **Standard Outputs (4x):** Open-drain, PWM-capable (PIN_OUT_1 to PIN_OUT_4)
  - 8-bit PWM resolution (standard Arduino PWM)
- **Heater Output (1x):** High-current, slow PWM (PIN_HEAT_OUT)
  - Custom TCC0 timer configuration
  - 1Hz PWM frequency for SSR control
  - 117187 period value (120MHz / 1024 prescaler / 1Hz)

### 6.5 GPIO
- **Main GPIO:** 8 pins (PIN_GPIO_0 to PIN_GPIO_7)
- **Expansion GPIO:** 15 pins (PIN_SP_IO_0 to PIN_SP_IO_14)
- **Features:**
  - Configurable input/output per pin
  - Pullup enable/disable
  - Runtime reconfiguration via `configChanged` flag

### 6.6 Modbus RTU Communication

#### 6.6.1 Custom Modbus Library
Located in `lib/modbus-rtu-master/`, key features:
- **Non-blocking operation** with FIFO queue (10 requests max)
- **RS485 support** with DE/RE pin control
- **All standard Modbus functions:** 0x01-0x06, 0x0F, 0x10
- **Callback-based responses** for async operation
- **CRC validation** and timeout handling
- **Critical fixes applied** (from memories):
  - Time unit consistency (millis throughout)
  - Proper timeout calculations
  - Inter-frame delays (3.5 character times)

#### 6.6.2 Modbus Infrastructure
- **4 Modbus ports:**
  - Port 0: Serial2 (RS232)
  - Port 1: Serial3 (RS232)
  - Port 2: Serial4 (RS485 with PIN_RS485_DE_1)
  - Port 3: Serial5 (RS485 with PIN_RS485_DE_2)
- **Runtime configuration** via `configChanged` flag
- **Flexible baud rates and serial config** (stop bits, parity, data bits)

#### 6.6.3 Peripheral Driver Architecture (Class-Based)

**Design Philosophy:**
- **Onboard drivers** (in `drivers/onboard/`): Fixed hardware on PCB, single-instance, struct-based
- **Peripheral drivers** (in `drivers/peripheral/`): External devices, multi-instance support via C++ classes

**Class-Based Peripheral Drivers:**

##### HamiltonPHProbe Class
- **Location:** `drivers/peripheral/drv_modbus_hamilton_ph.*`
- **Interface:** Modbus RTU slave device
- **Register Map:**
  - 2089: pH value (IEEE 754 float, 2 registers)
  - 2409: Temperature (IEEE 754 float, 2 registers)
- **Key Methods:**
  - `HamiltonPHProbe(ModbusDriver_t*, slaveID)` - Constructor
  - `update()` - Queue Modbus requests for pH and temperature
  - `getPhSensor()` - Get PhSensor_t reference
  - `getTemperatureSensor()` - Get TemperatureSensor_t reference
  - `hasFault()` - Check if either sensor has a fault
  - `hasNewMessage()` - Check if there's a new message
  - `getMessage()` - Get message string (prioritizes faults)
  - `clearMessages()` - Clear message flags
- **Features:**
  - Multiple instance support (create as many probes as needed)
  - Non-blocking via callbacks
  - Automatic unit reading from Hamilton unit code
  - Slave ID configurable per instance
  - Unified fault/message interface
  - Uses static callback trampolines for instance routing
- **Typical update rate:** 2000ms

##### HamiltonArcDO Class
- **Location:** `drivers/peripheral/drv_modbus_hamilton_arc_do.*`
- **Interface:** Modbus RTU slave device
- **Register Map:**
  - 2089 (PMC 1): Dissolved Oxygen value with units (IEEE 754 float, 10 registers)
  - 2409 (PMC 6): Temperature with units (IEEE 754 float, 10 registers)
- **Key Methods:**
  - `HamiltonArcDO(ModbusDriver_t*, slaveID)` - Constructor
  - `update()` - Queue Modbus requests for DO and temperature
  - `getDOSensor()` - Get DissolvedOxygenSensor_t reference
  - `getTemperatureSensor()` - Get TemperatureSensor_t reference
  - `hasFault()` - Check if either sensor has a fault
  - `hasNewMessage()` - Check if there's a new message
  - `getMessage()` - Get message string (prioritizes faults)
  - `clearMessages()` - Clear message flags
- **Features:**
  - Multiple instance support (create as many DO sensors as needed)
  - Non-blocking via callbacks
  - Automatic unit reading from Hamilton unit code
  - Slave ID configurable per instance
  - Unified fault/message interface
  - Uses static callback trampolines for instance routing
- **Typical update rate:** 2000ms

##### HamiltonArcOD Class
- **Location:** `drivers/peripheral/drv_modbus_hamilton_arc_od.*`
- **Interface:** Modbus RTU slave device
- **Register Map:**
  - 2089 (PMC 1): Optical Density value with units (IEEE 754 float, 10 registers)
  - 2409 (PMC 6): Temperature with units (IEEE 754 float, 10 registers)
- **Key Methods:**
  - `HamiltonArcOD(ModbusDriver_t*, slaveID)` - Constructor
  - `update()` - Queue Modbus requests for OD and temperature
  - `getODSensor()` - Get OpticalDensitySensor_t reference
  - `getTemperatureSensor()` - Get TemperatureSensor_t reference
  - `hasFault()` - Check if either sensor has a fault
  - `hasNewMessage()` - Check if there's a new message
  - `getMessage()` - Get message string (prioritizes faults)
  - `clearMessages()` - Clear message flags
- **Features:**
  - Multiple instance support (create as many OD sensors as needed)
  - Non-blocking via callbacks
  - Automatic unit reading from Hamilton unit code
  - Slave ID configurable per instance
  - Unified fault/message interface
  - Uses static callback trampolines for instance routing
- **Typical update rate:** 2000ms

##### AlicatMFC Class
- **Location:** `drivers/peripheral/drv_modbus_alicat_mfc.*`
- **Interface:** Modbus RTU slave device
- **Register Map (starting at 1349):**
  - 1349: Setpoint (float)
  - 1351: Valve Drive (float)
  - 1353: Pressure (float)
  - 1355: Secondary Pressure (float)
  - 1357: Barometric Pressure (float)
  - 1359: Temperature (float)
  - 1361: Volumetric Flow (float)
  - 1363: Mass Flow (float)
- **Key Methods:**
  - `AlicatMFC(ModbusDriver_t*, slaveID)` - Constructor
  - `update()` - Queue Modbus request for sensor data
  - `writeSetpoint(float)` - Write new setpoint with automatic validation
  - `getFlowSensor()` - Get FlowSensor_t reference
  - `getPressureSensor()` - Get PressureSensor_t reference
  - `getSetpoint()` - Get current setpoint
  - `hasFault()`, `hasNewMessage()`, `clearMessage()` - Message handling
- **Features:**
  - Multiple instance support (multiple MFCs on different slave IDs)
  - Setpoint write with automatic validation on next read
  - Automatic retry on write failure (up to 5 attempts)
  - Per-instance fault and message tracking
  - Uses static callback trampolines for instance routing
- **Typical update rate:** 2000ms

**Unified API Across All Peripheral Drivers:**

All peripheral device drivers share a consistent interface:
- `update()` - Non-blocking update method
- `getSlaveID()` - Get Modbus slave ID
- `hasFault()` - Check for fault condition
- `hasNewMessage()` - Check for new messages
- `getMessage()` - Get message string (prioritizes faults)
- `clearMessages()` or `clearMessage()` - Clear message flags

**Usage Example:**
```cpp
// Create instances (typically in main.cpp)
HamiltonPHProbe* phProbe1 = new HamiltonPHProbe(&modbusDriver[2], 3);
HamiltonPHProbe* phProbe2 = new HamiltonPHProbe(&modbusDriver[2], 4);
HamiltonArcDO* doSensor = new HamiltonArcDO(&modbusDriver[2], 5);
HamiltonArcOD* odSensor = new HamiltonArcOD(&modbusDriver[2], 6);
AlicatMFC* mfc1 = new AlicatMFC(&modbusDriver[3], 1);
AlicatMFC* mfc2 = new AlicatMFC(&modbusDriver[3], 2);

// Add to scheduler using lambda functions
tasks.addTask([]() { phProbe1->update(); }, 2000, true, false);
tasks.addTask([]() { doSensor->update(); }, 2000, true, false);
tasks.addTask([]() { odSensor->update(); }, 2000, true, false);
tasks.addTask([]() { mfc1->update(); }, 2000, true, false);

// Access sensor data
float pH = phProbe1->getPhSensor().ph;
const char* phUnit = phProbe1->getPhSensor().unit;
float dissolvedOxygen = doSensor->getDOSensor().dissolvedOxygen;
float opticalDensity = odSensor->getODSensor().opticalDensity;
float flow = mfc1->getFlowSensor().flow;

// Write setpoint to MFC
mfc1->writeSetpoint(50.0);

// Consistent fault/message handling across all devices
if (phProbe1->hasFault()) {
    Serial.printf("pH Probe Error: %s\n", phProbe1->getMessage());
    phProbe1->clearMessages();
}
if (mfc1->hasFault()) {
    Serial.printf("MFC Error: %s\n", mfc1->getMessage());
    mfc1->clearMessage();
}
```

### 6.7 Stepper Motor (TMC5130)
- **Communication:** SPI
- **Features:** StealthChop, configurable current, RPM control
- **Current state:** Commented out in main.cpp (not actively used)

### 6.8 DC Motors (DRV8235)
- **Count:** 4 motors
- **Features:** Bidirectional control, current feedback
- **Current state:** Partially implemented

### 6.9 Power Sensors (INA260)
- **Count:** 2 sensors
- **Communication:** I2C
- **Measures:** Voltage, current, power
- **Current state:** Driver present but not actively used

## 7. COMMUNICATION PORTS

### 7.1 Serial Ports
- **Serial (USB):** 115200 baud - Debug/monitoring
- **Serial2:** RS232 Port 1
- **Serial3:** RS232 Port 2
- **Serial4:** RS485 Port 1 (with DE/RE control)
- **Serial5:** RS485 Port 2 (with DE/RE control)

### 7.2 SPI Devices
All SPI devices share the main SPI bus but have individual CS pins:
- ADC (MCP3464): PIN_ADC_CS
- DAC (MCP48FEB): PIN_DAC_CS
- RTD 1-3 (MAX31865): PIN_PT100_CS_1/2/3
- Stepper (TMC5130): PIN_STP_CS

### 7.3 I2C Devices
- I2C bus: PIN_I2C_PER_SDA, PIN_I2C_PER_SCL
- Power sensors (INA260) on I2C

### 7.4 Inter-Processor Communication (IPC)
- **Interface:** Serial1 (UART)
- **Pins:** PIN_MI_TX (52), PIN_MI_RX (53)
- **Baud Rate:** 1,000,000 bps (1 Mbps)
- **Protocol:** Custom binary packet protocol with CRC16
- **Purpose:** Communication between SAME51 (this MCU) and RP2040 (management interface MCU)

**Key Features:**
- Binary packet framing with start/end markers (0x7E/0x7D)
- CRC16-CCITT error checking on all packets
- Byte stuffing for data transparency
- Non-blocking operation via task scheduler
- Message types for sensor data, control commands, device management, index synchronization
- Object index synchronization for dynamic device management
- Type-safe object references to prevent mismatches

**Data Flow:**
- **SAME51 → RP2040:** Sensor readings, fault notifications, device status
- **RP2040 → SAME51:** Control setpoints, device creation/deletion, configuration

**Documentation:** See `IPC_PROTOCOL_PLAN.md` for complete protocol specification

### 7.5 IPC Driver Architecture

**Driver Location:** `src/drivers/ipc/`

**State Machine Design:**
- **IDLE:** Waiting for start byte or processing TX queue
- **RECEIVING:** Collecting packet bytes with escape sequence handling
- **PROCESSING:** Validating CRC and dispatching to message handlers
- **ERROR:** Clearing buffers and returning to IDLE

**Key Components:**
```cpp
IPC_Driver_t {
    HardwareSerial *uart;           // Serial1 @ 1 Mbps
    IPC_State state;                // State machine
    uint8_t rxBuffer[1280];         // RX packet buffer
    IPC_TxPacket_t txQueue[8];      // TX queue (8 packets deep)
    // Statistics: rxPacketCount, txPacketCount, errors, CRC errors
}
```

**Packet Structure:**
- **8 bytes overhead:** START(1) + LENGTH(2) + MSG_TYPE(1) + CRC(2) + END(1)
- **Byte stuffing:** 0x7E and 0x7D escaped as 0x7D followed by (byte XOR 0x20)
- **CRC16-CCITT:** Polynomial 0x1021, covers LENGTH + MSG_TYPE + PAYLOAD

**Message Types (20+ defined):**
- **Handshake:** PING, PONG, HELLO, HELLO_ACK, ERROR
- **Index Sync:** INDEX_SYNC_REQ, INDEX_SYNC_DATA, INDEX_ADD, INDEX_REMOVE
- **Sensor Data:** SENSOR_READ_REQ, SENSOR_DATA, SENSOR_BATCH
- **Control:** CONTROL_WRITE, CONTROL_ACK, CONTROL_READ
- **Device Mgmt:** DEVICE_CREATE, DEVICE_DELETE, DEVICE_STATUS
- **Faults:** FAULT_NOTIFY, MESSAGE_NOTIFY, FAULT_CLEAR
- **Config:** CONFIG_READ, CONFIG_WRITE, CALIBRATE

**Performance:**
- **Task interval:** 5ms (high priority)
- **Expected CPU usage:** <0.5%
- **Throughput:** ~500 packets/second sustained
- **Latency:** <10ms for request/response

**Object Index Synchronization:**
- Indices 0-39: Fixed onboard hardware
- Indices 40-79: Dynamic peripheral devices
- Type-safe references (type must match in all operations)
- Nested sensor objects get separate indices (e.g., pH probe + pH sensor + temp sensor)

**RP2040 as Single Source of Truth:**
- Configuration data managed by RP2040
- Calibration data sent from RP2040 at startup
- Timestamps added by RP2040 (has RTC)
- SAME51 rebuilds state on boot from RP2040 commands

## 8. INITIALIZATION SEQUENCE

From `main.cpp setup()`:
1. Serial port (115200 baud)
2. CS pins initialization
3. Calibration data load from EEPROM
4. ADC initialization (continuous scan mode)
5. RTD sensors (3x, configured as needed)
6. DAC initialization (save to IC EEPROM)
7. ADC input unit configuration
8. Outputs initialization (standard + heater PWM)
9. GPIO initialization
10. Modbus initialization (4 ports)
11. Modbus port 2 reconfiguration (19200 baud, 2 stop bits for pH)
12. Modbus port 3 reconfiguration (19200 baud for MFC)
13. **IPC initialization (Serial1 @ 1 Mbps)**
14. Hamilton pH probe driver initialization
15. Alicat MFC driver initialization
16. Task creation and registration (including IPC task @ 5ms)
17. Enter main loop (tasks.update())

## 9. KEY DESIGN PATTERNS

### 9.1 Onboard Driver Structure Pattern
Onboard (fixed PCB hardware) drivers follow a struct-based pattern:
```cpp
// Object definitions
struct SensorType_t { ... };
SensorType_t sensorArray[N];

// Driver structure
struct DriverType_t {
    SensorType_t *objPointers[N];
    HardwareInterface *hardware;
    bool fault, newMessage;
    char message[100];
};
DriverType_t driver;

// Functions
bool init(void);      // Initialize hardware and objects
void update(void);    // Periodic update function
```

### 9.2 Peripheral Driver Class Pattern
Peripheral (external) drivers use C++ classes for multi-instance support:
```cpp
class PeripheralDevice {
public:
    // Constructor with modbus driver and slave ID
    PeripheralDevice(ModbusDriver_t *modbusDriver, uint8_t slaveID);
    
    // Public methods
    void update();                          // Non-blocking update
    SensorType_t& getSensorData();          // Access sensor objects
    
private:
    ModbusDriver_t *_modbusDriver;          // Pointer to modbus port
    uint8_t _slaveID;                       // Device slave ID
    SensorType_t _sensorData;               // Sensor data storage
    uint16_t _dataBuffer[SIZE];             // Modbus data buffer
    
    // Static callback trampoline pattern
    static PeripheralDevice* _currentInstance;
    static void responseCallback(bool valid, uint16_t *data);
    void handleResponse(bool valid, uint16_t *data);
};
```

**Key aspects of peripheral class pattern:**
- **Multiple instances:** Each device is an independent object
- **Static callback trampolines:** Required because Modbus callbacks must be static functions
- **Instance tracking:** `_currentInstance` static pointer updated before each request
- **Encapsulation:** All device-specific logic contained in class
- **Standard sensor objects:** Uses same `SensorType_t` structs as onboard drivers

### 9.3 Forward Declarations
Used to avoid circular includes (e.g., in `drv_modbus_hamilton_ph.h`):
```cpp
struct ModbusDriver_t;  // Forward declaration
class HamiltonPHProbe {
    ModbusDriver_t *_modbusDriver;  // Pointer to avoid include
    ...
};
```

### 9.4 Struct Member Access
**Critical pattern** (from memory):
- `modbusDriver` is a **pointer** to `ModbusDriver_t`
- `modbus` is a **member** (not pointer) of `ModbusDriver_t`
- Correct syntax: `modbusDriver->modbus.method()`

## 10. CPU USAGE MONITORING

The custom Scheduler library tracks CPU usage:
- **Per-task monitoring** via `getCpuUsagePercent()`
- **System-wide total** via `getTotalCpuUsagePercent()`
- **10-second rolling window**
- **Microsecond precision** execution time tracking
- Statistics: last, min, max, average execution time

Current implementation in main.cpp prints comprehensive CPU reports every 1000ms.

## 11. KNOWN ISSUES & NOTES

### 11.1 From Memories
1. **Modbus timing issues fixed:**
   - Time unit consistency
   - Proper inter-frame delays
   - Correct timeout calculations

2. **Pointer syntax in Modbus drivers:**
   - Correct: `modbusDriver->modbus.method()`
   - Wrong: `modbusDriver.modbus->method()`

### 11.2 From Code Review
1. **Main.cpp is debug-heavy** - lots of testing code
2. **Some drivers disabled** - Stepper, DC motors, power sensors commented out
3. **Float printf support** - Uses `asm(".global _printf_float")` for float formatting
4. **Memory allocation** - Some dynamic allocation in Modbus single-write functions (noted in README)

## 12. FUTURE EXPANSION

The system is designed for expansion:
- Object index supports up to 80 objects
- 20 calibration slots (currently using ~15)
- Unused object types defined (DO, OD, optical density control, etc.)
- Template for adding new Modbus devices
- Reserved spare GPIO pins (15)

## 13. CRITICAL CONSTANTS

### 13.1 ADC Constants
```cpp
#define ADC_V_DIV_RATIO     5.024
#define ADC_uV_PER_LSB      314.0
#define ADC_mV_PER_LSB      0.314
#define ADC_V_PER_LSB       0.000314
#define ADC_mA_PER_LSB      0.001308333  // 240Ω resistor
```

### 13.2 DAC Constants
```cpp
#define DAC_RANGE         4095
#define VREF_mV           2048
#define OP_AMP_GAIN       5
#define VOUT_MAX_mV       10240
#define mV_PER_LSB        2.50
```

### 13.3 Heater PWM
```cpp
#define HEATER_PWM_PERIOD 117187  // 120MHz / 1024 / 1Hz - 1
```

### 13.4 Modbus Timing
```cpp
#define MODBUS_DEFAULT_TIMEOUT 1000  // ms
#define MODBUS_DEFAULT_INTERFRAME_DELAY 3500  // µs
```

## 14. DEPENDENCIES

- **Arduino Framework** for SAMD
- **SPI** (hardware peripheral)
- **Wire** (I2C)
- **FlashStorage_SAMD** (EEPROM emulation)
- **Standard C++ library** (vector, algorithm for Scheduler)

---

**Note:** This document reflects the project state as of 2025-10-04. Refer to git history for changes.

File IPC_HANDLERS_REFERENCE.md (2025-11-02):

# IPC Handlers Reference

Complete guide to IPC message handlers for device integration.

---

## Overview

IPC (Inter-Processor Communication) handlers process messages between SYS MCU and IO MCU. For device integration, you need to implement:

1. **Sensor Read Handler** - Read control/sensor objects
2. **Device Control Handler** - Execute control commands
3. **Device Config Handler** - Apply configuration changes

---

## File: `orc-io-mcu/src/drivers/ipc/ipc_handlers.cpp`

---

## 1. Sensor Read Handler

Handles `IPC_MSG_SENSOR_READ_REQ` - reads object data for IPC transmission.

### Add Control Object Handler

Add to `ipc_handle_sensor_read_req()` switch statement:

```cpp
case OBJ_T_DEVICE_CONTROL: {
    DeviceControl_t *ctrl = (DeviceControl_t*)obj;
    
    // Primary value: Setpoint
    data.value = ctrl->setpoint;
    strncpy(data.unit, ctrl->setpointUnit, sizeof(data.unit) - 1);
    
    // Additional value: Actual value (if different from setpoint)
    if (ctrl->actualValue != ctrl->setpoint) {
        data.valueCount = 1;
        data.additionalValues[0] = ctrl->actualValue;
        strncpy(data.additionalUnits[0], ctrl->setpointUnit, 
                sizeof(data.additionalUnits[0]) - 1);
    }
    
    // Set flags for status
    if (ctrl->fault) {
        data.flags |= IPC_SENSOR_FLAG_FAULT;
    }
    if (!ctrl->connected) {
        data.flags |= IPC_SENSOR_FLAG_FAULT;  // Treat disconnected as fault
    }
    if (ctrl->newMessage) {
        data.flags |= IPC_SENSOR_FLAG_NEW_MSG;
        strncpy(data.message, ctrl->message, sizeof(data.message) - 1);
    }
    
    break;
}
```

**What this does:**
- Sends setpoint as primary value
- Sends actual value as additional value
- Sets fault flag if device has fault OR is disconnected
- Includes message if available

**Called by:** Background polling on SYS MCU (every 1 second)

---

## 2. Device Control Handler

Handles `IPC_MSG_DEVICE_CONTROL` - executes control commands.

### Required Includes

Add at top of file:
```cpp
#include "../peripheral/drv_modbus_alicat_mfc.h"
#include "../peripheral/drv_modbus_hamilton_ph.h"
// ... add includes for all your devices
```

### Main Handler Function

Already exists - you just add your device case:

```cpp
void ipc_handle_device_control(const uint8_t *payload, uint16_t len) {
    // Parse command
    const IPC_DeviceControlCmd_t* cmd = (const IPC_DeviceControlCmd_t*)payload;
    
    // Validate command structure
    if (len != sizeof(IPC_DeviceControlCmd_t)) {
        char errMsg[100];
        sprintf(errMsg, "Invalid size: got %d, expected %d", 
                len, sizeof(IPC_DeviceControlCmd_t));
        Serial.printf("[IPC] ERROR: %s\n", errMsg);
        ipc_sendError(IPC_ERR_PARSE_FAIL, errMsg);
        return;
    }
    
    // Get control object
    if (cmd->index < 50 || cmd->index >= 70) {
        Serial.printf("[DEV CTRL] ERROR: Invalid control index %d (must be 50-69)\n", 
                     cmd->index);
        ipc_sendError(IPC_ERR_PARAM_INVALID, "Control index must be 50-69");
        return;
    }
    
    ObjIndexEntry* entry = &objIndex[cmd->index];
    if (!entry->inUse || entry->objType != OBJ_T_DEVICE_CONTROL) {
        Serial.printf("[DEV CTRL] ERROR: No control object at index %d\n", cmd->index);
        ipc_sendError(IPC_ERR_PARAM_INVALID, "No control object at index");
        return;
    }
    
    DeviceControl_t* control = (DeviceControl_t*)entry->obj;
    
    // Response variables
    bool success = false;
    uint8_t errorCode = CTRL_ERR_NONE;
    char message[100] = "";
    
    // Dispatch based on command type
    switch(cmd->command) {
        case DEV_CMD_SET_SETPOINT: {
            // ... (see next section)
            break;
        }
        
        case DEV_CMD_RESET_FAULT: {
            // ... (see next section)
            break;
        }
        
        default:
            Serial.printf("[DEV CTRL] ERROR: Unknown command %d\n", cmd->command);
            errorCode = CTRL_ERR_INVALID_CMD;
            strcpy(message, "Unknown device control command");
            break;
    }
    
    // Send acknowledgment
    ipc_sendControlAck(cmd->index, cmd->objectType, cmd->command, 
                         success, errorCode, message);
}
```

### Add Your Device: SET_SETPOINT Command

Add inside `DEV_CMD_SET_SETPOINT` case:

```cpp
case DEV_CMD_SET_SETPOINT: {
    // Find device instance from control index
    ManagedDevice* dev = DeviceManager::findDeviceByControlIndex(cmd->index);
    if (!dev) {
        Serial.printf("[DEV CTRL] ERROR: No device found for control index %d\n", 
                     cmd->index);
        errorCode = CTRL_ERR_INVALID_INDEX;
        strcpy(message, "Device not found");
        break;
    }
    
    // Dispatch to device-specific handler based on device type
    switch(control->deviceType) {
        // ================================================================
        // YOUR DEVICE HANDLER
        // ================================================================
        case IPC_DEV_ALICAT_MFC: {
            Serial.printf("[DEV CTRL] Set MFC setpoint: index=%d, value=%.2f\n", 
                         cmd->index, cmd->setpoint);
            
            // Get device instance
            AlicatMFC* mfc = (AlicatMFC*)dev->deviceInstance;
            if (!mfc) {
                Serial.printf("[DEV CTRL] ERROR: MFC device instance is null\n");
                errorCode = CTRL_ERR_DRIVER_FAULT;
                strcpy(message, "MFC device instance not found");
                break;
            }
            
            // Store setpoint in control object for immediate feedback
            control->setpoint = cmd->setpoint;
            
            // Write setpoint to hardware via driver
            bool writeSuccess = mfc->writeSetpoint(cmd->setpoint);
            if (writeSuccess) {
                success = true;
                snprintf(message, sizeof(message), 
                        "Setpoint %.2f SLPM sent to MFC", cmd->setpoint);
                Serial.printf("[DEV CTRL] MFC setpoint command queued successfully\n");
            } else {
                success = false;
                errorCode = CTRL_ERR_DRIVER_FAULT;
                strcpy(message, "Failed to queue setpoint command");
                Serial.printf("[DEV CTRL] ERROR: Failed to queue MFC setpoint\n");
            }
            break;
        }
        
        // ================================================================
        // ADD MORE DEVICES HERE
        // ================================================================
        case IPC_DEV_PRESSURE_CTRL: {
            // Similar pattern for pressure controller
            PressureController* pc = (PressureController*)dev->deviceInstance;
            // ... validate ...
            control->setpoint = cmd->setpoint;
            if (pc->writeSetpoint(cmd->setpoint)) {
                success = true;
                snprintf(message, sizeof(message), 
                        "Setpoint %.2f PSI sent", cmd->setpoint);
            } else {
                errorCode = CTRL_ERR_DRIVER_FAULT;
                strcpy(message, "Failed to set pressure");
            }
            break;
        }
        
        // ================================================================
        // SENSOR-ONLY DEVICES (DON'T SUPPORT SETPOINT)
        // ================================================================
        case IPC_DEV_HAMILTON_PH:
        case IPC_DEV_HAMILTON_DO:
        case IPC_DEV_HAMILTON_OD: {
            Serial.printf("[DEV CTRL] ERROR: Device type %d does not support setpoint\n", 
                         control->deviceType);
            errorCode = CTRL_ERR_INVALID_CMD;
            strcpy(message, "Device does not support setpoint control");
            break;
        }
        
        default:
            Serial.printf("[DEV CTRL] ERROR: Unknown device type %d\n", 
                         control->deviceType);
            errorCode = CTRL_ERR_TYPE_MISMATCH;
            strcpy(message, "Unknown device type");
            break;
    }
    break;
}
```

### RESET_FAULT Command

Already implemented generically - no device-specific code needed:

```cpp
case DEV_CMD_RESET_FAULT: {
    control->fault = false;
    control->newMessage = false;
    strcpy(control->message, "Fault cleared");
    success = true;
    strcpy(message, "Fault reset");
    Serial.printf("[DEV CTRL] Fault cleared for device at index %d\n", cmd->index);
    break;
}
```

---

## 3. Command Response

Acknowledgment is sent automatically:

```cpp
ipc_sendControlAck(
    cmd->index,        // Control index (50-69)
    cmd->objectType,   // OBJ_T_DEVICE_CONTROL
    cmd->command,      // Command that was executed
    success,           // true if successful
    errorCode,         // Error code if failed
    message            // Human-readable message
);
```

**What happens:**
1. SYS MCU receives acknowledgment
2. Logs success or error
3. Returns HTTP response to Web UI
4. Next poll shows updated values

---

## Error Codes Reference

```cpp
// Success
CTRL_ERR_NONE = 0x00

// Client errors (4xx equivalent)
CTRL_ERR_INVALID_INDEX = 0x01    // Control index not found
CTRL_ERR_TYPE_MISMATCH = 0x02    // Wrong device type for command
CTRL_ERR_INVALID_CMD = 0x03      // Unknown command code
CTRL_ERR_OUT_OF_RANGE = 0x04     // Setpoint outside valid range
CTRL_ERR_NOT_ENABLED = 0x05      // Device not enabled

// Server errors (5xx equivalent)
CTRL_ERR_DRIVER_FAULT = 0x06     // Device driver error
CTRL_ERR_TIMEOUT = 0x07          // Communication timeout
```

**Usage:**
```cpp
// Validation error
if (setpoint < 0 || setpoint > 200) {
    errorCode = CTRL_ERR_OUT_OF_RANGE;
    strcpy(message, "Setpoint must be 0-200 SLPM");
    break;
}

// Driver error
if (!mfc->writeSetpoint(setpoint)) {
    errorCode = CTRL_ERR_DRIVER_FAULT;
    strcpy(message, "Failed to queue command");
    break;
}

// Success
success = true;
errorCode = CTRL_ERR_NONE;
snprintf(message, sizeof(message), "Setpoint %.2f sent", setpoint);
```

---

## Flow Diagram

```
┌─────────────────────────────────────────────────────────────────┐
│ 1. User enters setpoint in Web UI → Clicks "Set"               │
└────────────┬────────────────────────────────────────────────────┘
             │
             ▼
┌─────────────────────────────────────────────────────────────────┐
│ 2. Web UI sends POST /api/device/52/setpoint                   │
│    Body: {"setpoint": 100.0}                                   │
└────────────┬────────────────────────────────────────────────────┘
             │
             ▼
┌─────────────────────────────────────────────────────────────────┐
│ 3. SYS MCU handleSetDeviceSetpoint() creates IPC command       │
│    - Command: DEV_CMD_SET_SETPOINT                             │
│    - Index: 52                                                  │
│    - Value: 100.0                                               │
└────────────┬────────────────────────────────────────────────────┘
             │
             ▼  (IPC_MSG_DEVICE_CONTROL via UART)
┌─────────────────────────────────────────────────────────────────┐
│ 4. IO MCU ipc_handle_device_control() receives command         │
│    - Validates control index (50-69)                           │
│    - Gets control object at index 52                           │
│    - Checks device type                                         │
└────────────┬────────────────────────────────────────────────────┘
             │
             ▼
┌─────────────────────────────────────────────────────────────────┐
│ 5. Dispatch to device handler (IPC_DEV_ALICAT_MFC)            │
│    - Find ManagedDevice by control index                       │
│    - Cast to AlicatMFC* instance                               │
│    - Call mfc->writeSetpoint(100.0)                            │
└────────────┬────────────────────────────────────────────────────┘
             │
             ▼
┌─────────────────────────────────────────────────────────────────┐
│ 6. Driver queues command                                        │
│    - Sets _pendingSetpoint = 100.0                             │
│    - Sets _setpointPending = true                              │
│    - Updates _controlObj.setpoint = 100.0                      │
│    - Returns true                                               │
└────────────┬────────────────────────────────────────────────────┘
             │
             ▼
┌─────────────────────────────────────────────────────────────────┐
│ 7. Send IPC acknowledgment                                      │
│    ipc_sendControlAck(52, success=true, "Setpoint sent")    │
└────────────┬────────────────────────────────────────────────────┘
             │
             ▼  (IPC_MSG_CONTROL_ACK via UART)
┌─────────────────────────────────────────────────────────────────┐
│ 8. SYS MCU receives ACK                                         │
│    - Logs: "Device setpoint set: control[52] = 100.0"          │
│    - Returns HTTP 200 {"success": true}                        │
└────────────┬────────────────────────────────────────────────────┘
             │
             ▼
┌─────────────────────────────────────────────────────────────────┐
│ 9. Web UI receives success response                            │
│    - Shows success toast                                        │
│    - Next poll (2 sec) shows updated values                    │
└─────────────────────────────────────────────────────────────────┘

Meanwhile on IO MCU:
┌─────────────────────────────────────────────────────────────────┐
│ 10. Scheduler calls mfc->update() (next 2 sec cycle)           │
│     - State machine sees _setpointPending = true               │
│     - Transitions to WRITING_SETPOINT                          │
│     - Sends Modbus write to hardware                           │
│     - Waits for confirmation                                    │
│     - Updates _controlObj.actualValue when confirmed           │
└─────────────────────────────────────────────────────────────────┘
```

---

## Testing Serial Output

### Normal Operation

```
[DEV CTRL] Set MFC setpoint: index=52, value=100.00
[DEV CTRL] MFC setpoint command queued successfully
[IPC] Control ACK sent: index=52, success=1
[ALICAT MFC] Setpoint write sent: 100.00 SLPM
[ALICAT MFC] Flow: 99.8 SLPM, Temp: 23.5 °C
```

### Device Not Found

```
[DEV CTRL] Set MFC setpoint: index=52, value=100.00
[DEV CTRL] ERROR: No device found for control index 52
[IPC] Control ACK sent: index=52, success=0, error=0x01
```

### Driver Failure

```
[DEV CTRL] Set MFC setpoint: index=52, value=100.00
[ALICAT MFC] Invalid setpoint: 250.00 (range: 0-200)
[DEV CTRL] ERROR: Failed to queue MFC setpoint command
[IPC] Control ACK sent: index=52, success=0, error=0x06
```

### Communication Timeout

```
[ALICAT MFC] Setpoint write sent: 100.00 SLPM
[ALICAT MFC] Timeout waiting for response
[ALICAT MFC] FAULT: Communication timeout (3 retries)
[IPC] Sensor data sent: index=52, fault=1
```

---

## Complete Handler Template

```cpp
case IPC_DEV_YOUR_DEVICE: {
    Serial.printf("[DEV CTRL] Set device setpoint: index=%d, value=%.2f\n", 
                 cmd->index, cmd->setpoint);
    
    // 1. Get device instance
    YourDevice* device = (YourDevice*)dev->deviceInstance;
    if (!device) {
        Serial.printf("[DEV CTRL] ERROR: Device instance is null\n");
        errorCode = CTRL_ERR_DRIVER_FAULT;
        strcpy(message, "Device instance not found");
        break;
    }
    
    // 2. Validate setpoint range (optional but recommended)
    if (cmd->setpoint < MIN_VALUE || cmd->setpoint > MAX_VALUE) {
        Serial.printf("[DEV CTRL] ERROR: Setpoint out of range: %.2f\n", 
                     cmd->setpoint);
        errorCode = CTRL_ERR_OUT_OF_RANGE;
        snprintf(message, sizeof(message), 
                "Setpoint must be %.0f-%.0f %s", 
                MIN_VALUE, MAX_VALUE, control->setpointUnit);
        break;
    }
    
    // 3. Update control object immediately for UI feedback
    control->setpoint = cmd->setpoint;
    
    // 4. Call device driver method
    bool writeSuccess = device->writeSetpoint(cmd->setpoint);
    
    // 5. Set response based on result
    if (writeSuccess) {
        success = true;
        snprintf(message, sizeof(message), 
                "Setpoint %.2f %s sent to device", 
                cmd->setpoint, control->setpointUnit);
        Serial.printf("[DEV CTRL] Device setpoint command queued successfully\n");
    } else {
        success = false;
        errorCode = CTRL_ERR_DRIVER_FAULT;
        strcpy(message, "Failed to queue setpoint command");
        Serial.printf("[DEV CTRL] ERROR: Failed to queue setpoint\n");
    }
    break;
}
```

---

## Common Mistakes to Avoid

### 1. ❌ Calling device method without validation
```cpp
// BAD - will crash if device is null
AlicatMFC* mfc = (AlicatMFC*)dev->deviceInstance;
mfc->writeSetpoint(cmd->setpoint);  // CRASH!
```

```cpp
// GOOD - check for null first
AlicatMFC* mfc = (AlicatMFC*)dev->deviceInstance;
if (!mfc) {
    errorCode = CTRL_ERR_DRIVER_FAULT;
    strcpy(message, "Device instance not found");
    break;
}
bool success = mfc->writeSetpoint(cmd->setpoint);
```

### 2. ❌ Forgetting to update control object
```cpp
// BAD - UI won't show new setpoint until next device update
mfc->writeSetpoint(cmd->setpoint);
```

```cpp
// GOOD - UI gets immediate feedback
control->setpoint = cmd->setpoint;  // Update first!
mfc->writeSetpoint(cmd->setpoint);
```

### 3. ❌ Wrong error code for situation
```cpp
// BAD - misleading error
if (!mfc) {
    errorCode = CTRL_ERR_TIMEOUT;  // Not a timeout!
}
```

```cpp
// GOOD - correct error code
if (!mfc) {
    errorCode = CTRL_ERR_DRIVER_FAULT;  // Driver issue
}
if (setpoint > 200) {
    errorCode = CTRL_ERR_OUT_OF_RANGE;  // Validation issue
}
```

### 4. ❌ Not including device header
```cpp
// BAD - compile error
AlicatMFC* mfc = (AlicatMFC*)dev->deviceInstance;
// error: 'AlicatMFC' was not declared in this scope
```

```cpp
// GOOD - include at top of file
#include "../peripheral/drv_modbus_alicat_mfc.h"
```

---

## Checklist

Before testing your IPC handlers:

- [ ] Added device header include at top of file
- [ ] Added `OBJ_T_DEVICE_CONTROL` case in sensor read handler
- [ ] Added device case in `DEV_CMD_SET_SETPOINT` handler
- [ ] Validated device instance pointer before use
- [ ] Updated control object setpoint immediately
- [ ] Called device `writeSetpoint()` method
- [ ] Set appropriate error codes
- [ ] Provided descriptive messages
- [ ] Added serial logging for debugging
- [ ] Tested with actual hardware or simulator

---

**With these handlers in place, your device is fully integrated into the IPC control system!**

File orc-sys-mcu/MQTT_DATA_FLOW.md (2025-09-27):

# ORC System MQTT Data Flow & Topic Registry

This document describes how sensor data is published from the Open Reactor Control System (ORC) to an MQTT broker, including topic structure, payload format, and sensor mapping.

---

## MQTT Topic Structure

The ORC system publishes two types of sensor data:

### 1. External Sensor Data (from I/O Controller via IPC)
| Sensor Type | Topic Prefix | Example Topic |
|---|---|---|
| Power | orcs/sensors/power | orcs/sensors/power/0 |
| Temperature | orcs/sensors/temperature | orcs/sensors/temperature/0 |
| pH | orcs/sensors/ph | orcs/sensors/ph/0 |
| Dissolved Oxygen | orcs/sensors/do | orcs/sensors/do/0 |
| Optical Density | orcs/sensors/od | orcs/sensors/od/0 |
| Gas Flow | orcs/sensors/gasflow | orcs/sensors/gasflow/0 |
| Pressure | orcs/sensors/pressure | orcs/sensors/pressure/0 |
| Stirrer Speed | orcs/sensors/stirrer | orcs/sensors/stirrer/0 |
| Weight | orcs/sensors/weight | orcs/sensors/weight/0 |

### 2. System Status Data (from RP2040 Controller)
| Data Type | Topic | Description |
|---|---|---|
| Power Voltage | orcs/system/power/voltage | Main PSU voltage (V) |
| 20V Rail | orcs/system/power/20v | 20V rail voltage (V) |
| 5V Rail | orcs/system/power/5v | 5V rail voltage (V) |
| PSU Status | orcs/system/status/psu_ok | PSU OK status (1=OK, 0=Fault) |
| 20V Status | orcs/system/status/20v_ok | 20V rail OK (1=OK, 0=Fault) |
| 5V Status | orcs/system/status/5v_ok | 5V rail OK (1=OK, 0=Fault) |
| SD Card Status | orcs/system/status/sdcard_ok | SD card OK (1=OK, 0=Fault) |
| IPC Status | orcs/system/status/ipc_ok | IPC OK (1=OK, 0=Fault) |
| RTC Status | orcs/system/status/rtc_ok | RTC OK (1=OK, 0=Fault) |
| Modbus Connection | orcs/system/status/modbus_connected | Modbus connected (1=Connected, 0=Not) |
| Modbus Busy | orcs/system/status/modbus_busy | Modbus busy (1=Busy, 0=Idle)  |
| Webserver Status | orcs/system/status/webserver_up | Webserver up (1=Up, 0=Down) |
| Webserver Busy | orcs/system/status/webserver_busy | Webserver busy (1=Busy, 0=Idle) |
| MQTT Connection | orcs/system/status/mqtt_connected | MQTT connected (1=Connected, 0=Not) |
| MQTT Busy | orcs/system/status/mqtt_busy | MQTT busy (1=Busy, 0=Idle) |

### 3. Consolidated Data Topics
| Topic | Description |
|---|---|
## MQTT Topic Structure

Topics are scoped per device using a prefix:

- Default: `orcs/dev/<MAC>` (e.g., `orcs/dev/AA:BB:CC:DD:EE:FF`)
- Override: `mqttDevicePrefix` in network config (`/api/mqtt`)

All topics below are relative to the device prefix unless stated as absolute.

The ORC system publishes two types of sensor data:
| orcs/system/sensors      | All system status data in one JSON payload    |

### 1. External Sensor Data (from I/O Controller via IPC)
| Sensor Type         | Topic Prefix (relative)     | Example Topic                  |
---
| Power               | orcs/sensors/power         | orcs/dev/<MAC>/orcs/sensors/power/0          |
| Temperature         | orcs/sensors/temperature   | orcs/dev/<MAC>/orcs/sensors/temperature/0    |
| pH                  | orcs/sensors/ph            | orcs/dev/<MAC>/orcs/sensors/ph/0             |
| Dissolved Oxygen    | orcs/sensors/do            | orcs/dev/<MAC>/orcs/sensors/do/0             |
| Optical Density     | orcs/sensors/od            | orcs/dev/<MAC>/orcs/sensors/od/0             |
| Gas Flow            | orcs/sensors/gasflow       | orcs/dev/<MAC>/orcs/sensors/gasflow/0        |
| Pressure            | orcs/sensors/pressure      | orcs/dev/<MAC>/orcs/sensors/pressure/0       |
| Stirrer Speed       | orcs/sensors/stirrer       | orcs/dev/<MAC>/orcs/sensors/stirrer/0        |
| Weight              | orcs/sensors/weight        | orcs/dev/<MAC>/orcs/sensors/weight/0         |

### External Sensor Data (IPC)
### 2. System Status Data (from RP2040 Controller)
| Data Type           | Topic (relative)                | Description                    |
- Data is received from the I/O Controller via IPC and immediately published to the MQTT broker.
| Power Voltage       | sensors/power/voltage          | Main PSU voltage (V)           |
| 20V Rail            | sensors/power/20v              | 20V rail voltage (V)           |
| 5V Rail             | sensors/power/5v               | 5V rail voltage (V)            |
| PSU Status          | status/psu_ok                  | PSU OK status (1=OK, 0=Fault) |
| 20V Status          | status/20v_ok                  | 20V rail OK (1=OK, 0=Fault)   |
| 5V Status           | status/5v_ok                   | 5V rail OK (1=OK, 0=Fault)    |
| SD Card Status      | status/sdcard_ok               | SD card OK (1=OK, 0=Fault)    |
| IPC Status          | status/ipc_ok                  | IPC OK (1=OK, 0=Fault)        |
| RTC Status          | status/rtc_ok                  | RTC OK (1=OK, 0=Fault)        |
| Modbus Connection   | status/modbus_connected        | Modbus connected (1=Connected, 0=Not) |
| Modbus Busy         | status/modbus_busy             | Modbus busy (1=Busy, 0=Idle)  |
| Webserver Status    | status/webserver_up            | Webserver up (1=Up, 0=Down)   |
| Webserver Busy      | status/webserver_busy          | Webserver busy (1=Busy, 0=Idle) |
| MQTT Connection     | status/mqtt_connected          | MQTT connected (1=Connected, 0=Not) |
| MQTT Busy           | status/mqtt_busy               | MQTT busy (1=Busy, 0=Idle)    |

## Example MQTT Payloads

### Individual Sensor Topic

### Individual Sensor Topic

**Note:** Sensor names are encoded in the MQTT topic path, not the payload. For example:

Topic: `orcs/dev/<MAC>/sensors/temperature/0`
Payload:
```json
{
  "timestamp": "2025-07-19T10:30:00Z",
  "value": 37.50,
  "online": true
}
```

If you want the sensor name in the payload, add a `"name"` field:
```json
{
  "timestamp": "2025-07-19T10:30:00Z",
  "value": 37.50,
  "online": true,
  "name": "temperature"
}
```

### Consolidated System Status Topic (`<devicePrefix>/sensors/all`)
Payload example:
```json
{
  "sensors": {
    "sensors/power/voltage": { "value": 23.62, "timestamp": "2025-07-18T14:23:45Z" },
    "sensors/power/20v": { "value": 19.93, "timestamp": "2025-07-18T14:23:45Z" },
    "status/psu_ok": { "value": 1.00, "timestamp": "2025-07-18T14:23:45Z" }
  }
}
```

## Data Flow Summary

### Subscribe to all external sensor data (all devices):
### External Sensors (via IPC)
mosquitto_sub -h broker -t "orcs/dev/+/orcs/sensors/#"
2. Data is sent to the System Controller (RP2040) via IPC.
3. RP2040 formats the data and publishes it to the MQTT broker on `orcs/sensors/` topics.
### Subscribe to all system status data for one device:
4. Each sensor type and instance is mapped to a unique topic for easy subscription and filtering.
mosquitto_sub -h broker -t "orcs/dev/<MAC>/status/#"
### System Status (RP2040 Local)
1. RP2040 controller monitors its own systems (power, network, storage, etc.).
### Subscribe to consolidated system status for one device:
2. Data is collected and formatted locally.
mosquitto_sub -h broker -t "orcs/dev/<MAC>/sensors/all"

---
### Subscribe to everything (all devices):

mosquitto_sub -h broker -t "orcs/dev/#"

### External Sensor Registry (IPC)
### Example Command to list all topics if IP is 10.10.37.118 (all devices)
```cpp
mosquitto_sub -h 10.10.37.118 -p 1883 -t "orcs/dev/#" -v
---

## Reliability Features

- Last Will and Testament (LWT): `<devicePrefix>/status/online` is retained `true` when connected; broker sets `false` on unexpected disconnect.
- KeepAlive: 30s; socket timeout: 15s; reconnect backoff: 5s.
- Buffer size: 1024 bytes to support JSON payloads.
- Configurable publish interval via `/api/mqtt` (`mqttPublishIntervalMs`).
    {MSG_POWER_SENSOR, "orcs/sensors/power"},
    {MSG_TEMPERATURE_SENSOR, "orcs/sensors/temperature"},
    {MSG_PH_SENSOR, "orcs/sensors/ph"},
    {MSG_DO_SENSOR, "orcs/sensors/do"},
    {MSG_OD_SENSOR, "orcs/sensors/od"},
    {MSG_GAS_FLOW_SENSOR, "orcs/sensors/gasflow"},
    {MSG_PRESSURE_SENSOR, "orcs/sensors/pressure"},
    {MSG_STIRRER_SPEED_SENSOR, "orcs/sensors/stirrer"},
    {MSG_WEIGHT_SENSOR, "orcs/sensors/weight"}
};
```

### System Status Registry (RP2040)
```cpp
MqttTopicEntry mqttTopics[] = {
    {"orcs/system/power/voltage", getVpsu, "Main PSU voltage (V)"},
    {"orcs/system/power/20v", getV20, "20V rail voltage (V)"},
    {"orcs/system/power/5v", getV5, "5V rail voltage (V)"},
    {"orcs/system/status/psu_ok", getPsuOK, "PSU OK status (1=OK, 0=Fault)"},
    // ... more status topics
};
```

---

## Notes
- All payloads are JSON and use ISO 8601 timestamps.
- **External sensor topics** (`orcs/sensors/`) are for actual sensor readings from the I/O controller.
- **System status topics** (`orcs/system/`) are for RP2040 controller health and status monitoring.
- Topics are designed for scalability and easy integration with external systems.
- The registry makes it simple to add new sensor types or instances.
- Both individual topics and consolidated topics are published for flexibility.

## Subscription Examples

### Subscribe to all external sensor data:
```bash
mosquitto_sub -h broker -t "orcs/sensors/#"
```

### Subscribe to all system status data:
```bash
mosquitto_sub -h broker -t "orcs/system/#"
```

### Subscribe to consolidated system status:
```bash
mosquitto_sub -h broker -t "orcs/system/sensors"
```

### Subscribe to everything:
```bash
mosquitto_sub -h broker -t "orcs/#"
```

### Example Command to list all topics if IP is 10.10.37.118
```bash
mosquitto_sub -h 10.10.37.118 -p 1883 -t "orcs/#" -v
```

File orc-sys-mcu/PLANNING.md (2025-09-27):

# Open Reactor Control System - MCU Architecture Overview

This document provides a high-level overview of the dual-microcontroller architecture for the Open Reactor Control System. It is intended to give context to developers and AI assistants working on the codebase.

The system is built on a **separation of concerns** principle, dividing tasks between a high-level **System Controller** and a real-time **I/O Controller**.

---

## 1. System Controller (RP2040): The "Brain"

This is the primary MCU for this codebase (`orc-sys-mcu`). It is responsible for all high-level tasks that are not strictly real-time.

*   **Hardware:** Raspberry Pi RP2040
*   **Core Philosophy:** Manages the user experience, network connectivity, and overall system state. It decides *what* should happen and *when*, but delegates the real-time execution to the I/O Controller.

### Primary Responsibilities:
*   **User Interface:** Hosts a web server (using `W5500lwIP` and `WebServer`) to serve the HTML, CSS, and JavaScript front-end.
*   **Network Management:** Handles all network communication, including:
    *   Ethernet connectivity (`lwIP`).
    *   REST APIs for UI interaction (`WebServer`, `ArduinoJson`).
    *   MQTT client for data publishing to the cloud/digital twin (`PubSubClient`).
    *   NTP for time synchronization.
*   **Data Logging & Storage:** Manages the SD card (`SdFat`) for logging system events and sensor data.
*   **High-Level Orchestration:** Runs the main logic for control sequences, recipes, and system modes.
*   **Configuration Management:** Loads and saves system settings (e.g., network, MQTT) from configuration files on the built-in LittleFS.
*   **Inter-Processor Communication (IPC):** Acts as the master in the communication link with the I/O Controller.

### RP2040 Dual-Core Usage:
*   **Core 0:** Dedicated to network-related tasks (`manageNetwork`, `manageMqtt`, WebServer client handling). This prevents network activity from blocking other system functions.
*   **Core 1:** Handles all other management tasks (status LEDs, power monitoring, terminal commands, IPC, SD card).

---

## 2. I/O Controller (SAMD51): The "Hands"

The I/O Controller is a separate MCU (with its own codebase) that handles all direct, real-time interactions with the physical world.

*   **Hardware:** SAM D51 (or similar powerful MCU)
*   **Core Philosophy:** Provides a hardware abstraction layer. It executes low-level commands received from the System Controller and reports back with sensor data and status. It is lean, fast, and deterministic.

### Primary Responsibilities:
*   **Real-Time Control Loops:** Executes time-critical PID loops for temperature, pH, etc.
*   **Direct Sensor Reading:** Interfaces directly with sensors via I2C, SPI, ADC, and one-wire protocols.
*   **Direct Actuator Control:** Manages PWM outputs for heaters, pumps, and valves, and digital outputs for other components.
*   **Hardware Safety Interlocks:** Implements low-level safety checks that must run without interruption (e.g., over-temperature cutoff).
*   **Inter-Processor Communication (IPC):** Acts as the slave, responding to requests from the System Controller.

---

## 3. Inter-Processor Communication (IPC): The "Nervous System"

The two MCUs communicate via a well-defined protocol.

*   **Physical Layer:** A dedicated UART bus (`Serial1` on the RP2040).
*   **Protocol:** A custom, packet-based protocol defined in `lib/IPCprotocol/`.
    *   **`IPCProtocol.h` / `.cpp`:** Implements the message framing, CRC checking, and dispatching.
    *   **`IPCDataStructs.h`:** Defines the exact data structures for all sensor readings and control setpoints. This file is **shared** between both the System Controller and I/O Controller projects to ensure they speak the same language.

**Example Data Flow (Setting Temperature):**
1.  User sets a new temperature in the web UI.
2.  The browser sends a `POST` request to the RP2040's web server.
3.  The RP2040 API handler parses the request.
4.  The RP2040 creates a `TemperatureControl` struct with the new setpoint.
5.  The RP2040 sends this struct to the SAMD51 using the IPC protocol.
6.  The SAMD51 receives the IPC message, validates it, and updates its internal PID loop setpoint.
7.  The SAMD51 periodically reads the temperature sensor and sends a `TemperatureSensor` struct back to the RP2040 via IPC.
8.  The RP2040 receives the sensor data, updates its global state, and makes it available to the UI (via WebSockets/REST) and MQTT.

This architecture ensures that the user interface and network stack remain responsive, even when the I/O Controller is busy with a high-frequency control task.

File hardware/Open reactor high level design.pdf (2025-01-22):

# Open bio-reactor system high level design

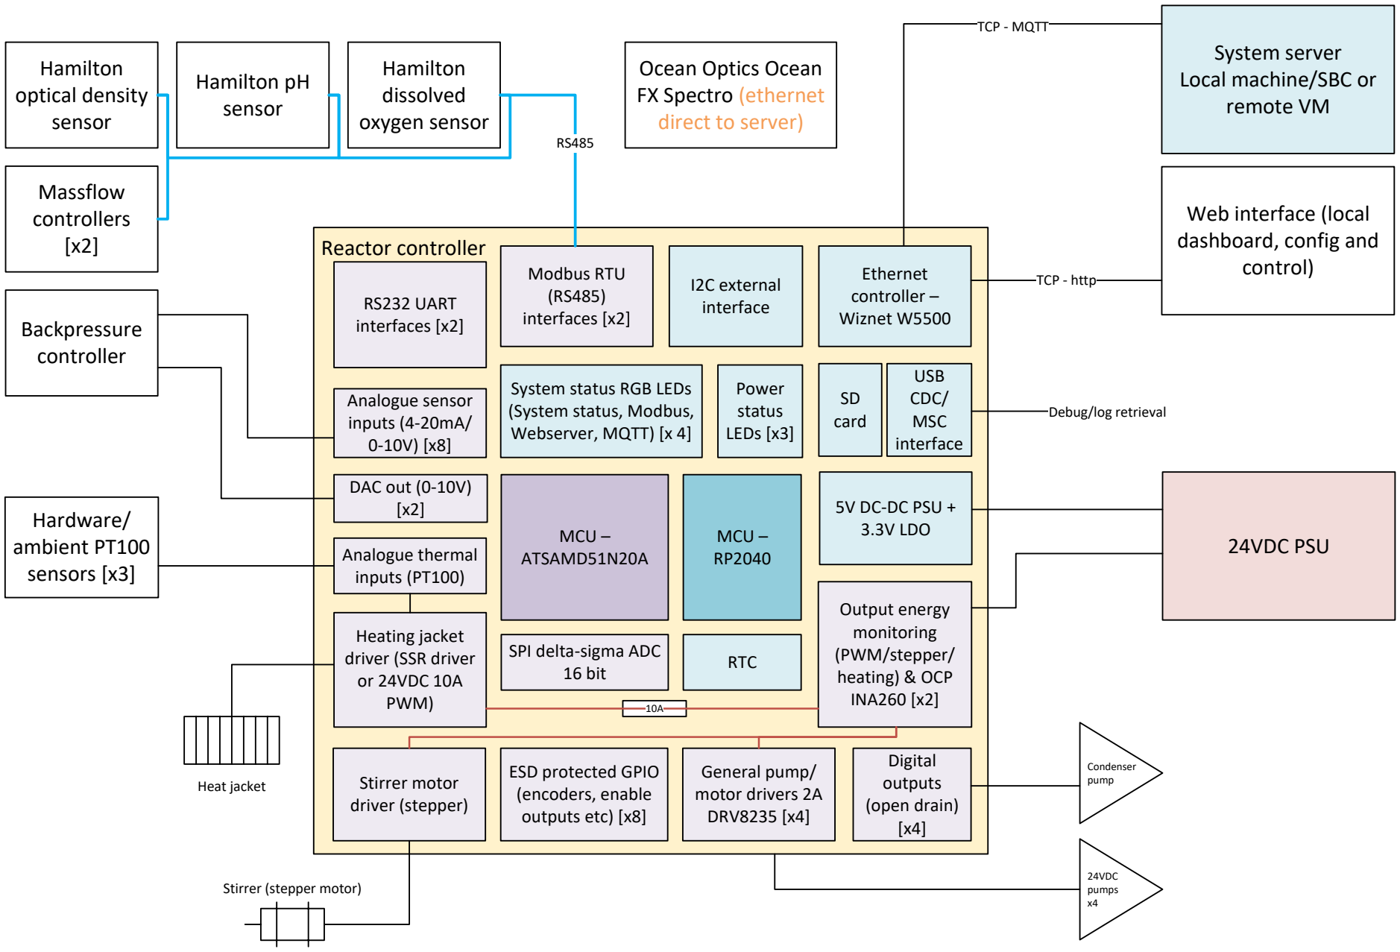
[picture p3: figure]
Reactor controller; System server Local machine/SBC or remote VM; TCP - MQTT; Ethernet controller – Wiznet W5500; MCU – ATSAMD51N20A; Web interface (local dashboard, config and control); TCP - http; 24VDC PSU; 5V DC-DC PSU + 3.3V LDO; USB CDC/ MSC interface; Debug/log retrieval; Digital outputs (open drain) [x4]; General pump/ motor drivers 2A DRV8235 [x4]; Heating jacket driver (SSR driver or 24VDC 10A PWM); 24VDC pumps x4; Condenser pump; Analogue thermal inputs (PT100); Modbus RTU (RS485) interfaces [x2]; Stirrer motor driver (stepper); Analogue sensor inputs (4-20mA/ 0-10V) [x8]; RS232 UART interfaces [x2]; Stirrer (stepper motor); Heat jacket; I2C external interface; Massflow controllers [x2]; Backpressure controller; Hamilton dissolved oxygen sensor; Hamilton pH sensor; Hamilton optical density sensor; Ocean Optics Ocean FX Spectro (ethernet direct to server); SPI delta-sigma ADC; 16 bit; RTC; Hardware/ ambient PT100 sensors [x3]; Power status LEDs [x3]; System status RGB LEDs (System status, Modbus, Webserver, MQTT) [x 4]; Output energy monitoring (PWM/stepper/ heating) & OCP INA260 [x2]; ESD protected GPIO (encoders, enable outputs etc) [x8]; SD card; DAC out (0-10V) [x2]; MCU – RP2040

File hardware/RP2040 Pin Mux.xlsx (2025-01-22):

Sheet: Pin mux table
RP2040 Pin Multiplex Table
Datasheet: | C:\Users\peake\Google Drive\Documents\Altium\MCU Templates & Datasheets\rp2040-datasheet.pdf |  |  |  |  |  |  |  |  |  |  |  |  | Application
Pin | I/O Pin | Name | ADC | F1 | F2 | F3 | F4 | F5 | F6 | F7 | F8 | F9 | Column1 | Net name | Description | Defines | Pin names (RP2040) | Peripheral | Notes
1 | - | IOVDD | - |  |  |  |  |  |  |  |  |  |  |  |  |  | ETH_MOSI | SPI0
2 | 0 | GPIO0 | - | SPI0 RX | UART0 TX | I2C0 SDA | PWM0 A | SIO | PIO0 | PIO1 |  | USB OVCUR DET |  | ETH_MISO |  | #define PIN_ETH_MISO 0 | ETH_MISO
3 | 1 | GPIO1 | - | SPI0 CSn | UART0 RX | I2C0 SCL | PWM0 B | SIO | PIO0 | PIO1 |  | USB VBUS DET |  | ETH_CS |  | #define PIN_ETH_CS 1 | ETH_SCK
4 | 2 | GPIO2 | - | SPI0 SCK | UART0 CTS | I2C1 SDA | PWM1 A | SIO | PIO0 | PIO1 |  | USB VBUS EN |  | ETH_SCK |  | #define PIN_ETH_SCK 2 | ETH_CS | GPIO
5 | 3 | GPIO3 | - | SPI0 TX | UART0 RTS | I2C1 SCL | PWM1 B | SIO | PIO0 | PIO1 |  | USB OVCUR DET |  | ETH_MOSI |  | #define PIN_ETH_MOSI 3 | ETH_RST
6 | 4 | GPIO4 | - | SPI0 RX | UART1 TX | I2C0 SDA | PWM2 A | SIO | PIO0 | PIO1 |  | USB VBUS DET |  | ETH_RST |  | #define PIN_ETH_RST 4 | ETH_IRQ
7 | 5 | GPIO5 | - | SPI0 CSn | UART1 RX | I2C0 SCL | PWM2 B | SIO | PIO0 | PIO1 |  | USB VBUS EN |  | ETH_IRQ |  | #define PIN_ETH_IRQ 5 | USB_D_P | USB
8 | 6 | GPIO6 | - | SPI0 SCK | UART1 CTS | I2C1 SDA | PWM3 A | SIO | PIO0 | PIO1 |  | USB OVCUR DET |  | RTC_SDA |  | #define PIN_RTC_SDA 6 | USB_D_N
9 | 7 | GPIO7 | - | SPI0 TX | UART1 RTS | I2C1 SCL | PWM3 B | SIO | PIO0 | PIO1 |  | USB VBUS DET |  | RTC_SCL |  | #define PIN_RTC_SCL 7 | SD_MOSI | SPI1/PIO
10 | - | IOVDD | - |  |  |  |  |  |  |  |  |  |  |  |  |  | SD_MISO |  | D0
11 | 8 | GPIO8 | - | SPI1 RX | UART1 TX | I2C0 SDA | PWM4 A | SIO | PIO0 | PIO1 |  | USB VBUS EN |  | I2C_EXT_SDA |  | #define PIN_I2C_EXT_SDA 8 | SD_SCK |  | D0 - 2
12 | 9 | GPIO9 | - | SPI1 CSn | UART1 RX | I2C0 SCL | PWM4 B | SIO | PIO0 | PIO1 |  | USB OVCUR DET |  | I2C_EXT_SCL |  | #define PIN_I2C_EXT_SCL 9 | SD_CS | GPIO/PIO | D0 + 3
13 | 10 | GPIO10 | - | SPI1 SCK | UART1 CTS | I2C1 SDA | PWM5 A | SIO | PIO0 | PIO1 |  | USB VBUS DET |  | SD_SCK | SDIO CLK | #define PIN_SD_SCK 10 | SD_CD
14 | 11 | GPIO11 | - | SPI1 TX | UART1 RTS | I2C1 SCL | PWM5 B | SIO | PIO0 | PIO1 |  | USB VBUS EN |  | SD_MOSI | SDIO CMD | #define PIN_SD_MOSI 11 | SD_DAT1 |  | D0 + 1
15 | 12 | GPIO12 | - | SPI1 RX | UART0 TX | I2C0 SDA | PWM6 A | SIO | PIO0 | PIO1 |  | USB OVCUR DET |  | SD_MISO | SDIO D0 | #define PIN_SD_MISO 12 | SD_DAT2 |  | D0 + 2
16 | 13 | GPIO13 | - | SPI1 CSn | UART0 RX | I2C0 SCL | PWM6 B | SIO | PIO0 | PIO1 |  | USB VBUS DET |  | SD_D1 | SDIO D1 | #define PIN_SD_D1 13 | I2C_EXT_SDA | I2C0
17 | 14 | GPIO14 | - | SPI1 SCK | UART0 CTS | I2C1 SDA | PWM7 A | SIO | PIO0 | PIO1 |  | USB VBUS EN |  | SD_D2 | SDIO D2 | #define PIN_SD_D2 14 | I2C_EXT_SCL
18 | 15 | GPIO15 | - | SPI1 TX | UART0 RTS | I2C1 SCL | PWM7 B | SIO | PIO0 | PIO1 |  | USB OVCUR DET |  | SD_CS | SDIO D3 | #define PIN_SD_CS 15 | LED_DAT | GPIO | PIO?
19 | - | TESTEN | - |  |  |  |  |  |  |  |  |  |  |  |  |  | PS_24V_FB | ADC
20 | - | XIN | - |  |  |  |  |  |  |  |  |  |  |  |  |  | PS_5V_FB
21 | - | XOUT | - |  |  |  |  |  |  |  |  |  |  |  |  |  | PS_3V3_FB
22 | - | IOVDD | - |  |  |  |  |  |  |  |  |  |  |  |  |  | RTC_SDA | I2C1
23 | - | DVDD | - |  |  |  |  |  |  |  |  |  |  |  |  |  | RTC_SCL
24 | - | SWCLK | - |  |  |  |  |  |  |  |  |  |  |  |  |  | MCU_HMI_TX | UART0
25 | - | SWDIO | - |  |  |  |  |  |  |  |  |  |  |  |  |  | MCU_HMI_RX
26 | - | RUN | -
27 | 16 | GPIO16 | - | SPI0 RX | UART0 TX | I2C0 SDA | PWM0 A | SIO | PIO0 | PIO1 |  | USB VBUS DET |  | SI_TX |  | #define PIN_SI_TX 16
28 | 17 | GPIO17 | - | SPI0 CSn | UART0 RX | I2C0 SCL | PWM0 B | SIO | PIO0 | PIO1 |  | USB VBUS EN |  | SI_RX |  | #define PIN_SI_RX 17
29 | 18 | GPIO18 | - | SPI0 SCK | UART0 CTS | I2C1 SDA | PWM1 A | SIO | PIO0 | PIO1 |  | USB OVCUR DET |  | SD_CD |  | #define PIN_SD_CD 18
30 | 19 | GPIO19 | - | SPI0 TX | UART0 RTS | I2C1 SCL | PWM1 B | SIO | PIO0 | PIO1 |  | USB VBUS DET |  | LED_DAT |  | #define PIN_LED_DAT 19
31 | 20 | GPIO20 | - | SPI0 RX | UART1 TX | I2C0 SDA | PWM2 A | SIO | PIO0 | PIO1 | CLOCK GPIN0 | USB VBUS EN |  | SP_IO_0 |  | #define PIN_SP_IO_0 20
32 | 21 | GPIO21 | - | SPI0 CSn | UART1 RX | I2C0 SCL | PWM2 B | SIO | PIO0 | PIO1 | CLOCK GPOUT0 | USB OVCUR DET |  | SP_IO_1 |  | #define PIN_SP_IO_1 21
33 | - | IOVDD | -
34 | 22 | GPIO22 | - | SPI0 SCK | UART1 CTS | I2C1 SDA | PWM3 A | SIO | PIO0 | PIO1 | CLOCK GPIN1 | USB VBUS DET |  | SP_IO_2 |  | #define PIN_SP_IO_2 22
35 | 23 | GPIO23 | - | SPI0 TX | UART1 RTS | I2C1 SCL | PWM3 B | SIO | PIO0 | PIO1 | CLOCK GPOUT1 | USB VBUS EN |  | SP_IO_3 |  | #define PIN_SP_IO_3 23
36 | 24 | GPIO24 | - | SPI1 RX | UART1 TX | I2C0 SDA | PWM4 A | SIO | PIO0 | PIO1 | CLOCK GPOUT2 | USB OVCUR DET |  | SP_IO_4 |  | #define PIN_SP_IO_4 24
37 | 25 | GPIO25 | - | SPI1 CSn | UART1 RX | I2C0 SCL | PWM4 B | SIO | PIO0 | PIO1 | CLOCK GPOUT3 | USB VBUS DET |  | SP_IO_5 |  | #define PIN_SP_IO_5 25
38 | 26 | GPIO26 | 0 | SPI1 SCK | UART1 CTS | I2C1 SDA | PWM5 A | SIO | PIO0 | PIO1 |  | USB VBUS EN |  | PS_24V_FB |  | #define PIN_PS_24V_FB 26
39 | 27 | GPIO27 | 1 | SPI1 TX | UART1 RTS | I2C1 SCL | PWM5 B | SIO | PIO0 | PIO1 |  | USB OVCUR DET |  | PS_20V_FB |  | #define PIN_PS_20V_FB 27
40 | 28 | GPIO28 | 2 | SPI1 RX | UART0 TX | I2C0 SDA | PWM6 A | SIO | PIO0 | PIO1 |  | USB VBUS DET |  | PS_5V_FB |  | #define PIN_PS_5V_FB 28
41 | 29 | GPIO29 | 3 | SPI1 CSn | UART0 RX | I2C0 SCL | PWM6 B | SIO | PIO0 | PIO1 |  | USB VBUS EN |  | SP_IO_6 |  | #define PIN_SP_IO_6 29
42 | - | IOVDD | -
43 | - | ADC_AVDD | -
44 | - | VREG_IN | -
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

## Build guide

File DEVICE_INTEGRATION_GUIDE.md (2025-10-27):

# Device Integration Guide

**Version:** 1.0  
**Last Updated:** October 2024  
**Purpose:** Complete reference for integrating new peripheral devices into the Open Reactor Control System

---

## Table of Contents

1. [Overview](#overview)
2. [Architecture Summary](#architecture-summary)
3. [Integration Checklist](#integration-checklist)
4. [Part 1: Device Driver (IO MCU)](#part-1-device-driver-io-mcu)
5. [Part 2: Device Manager (IO MCU)](#part-2-device-manager-io-mcu)
6. [Part 3: IPC Handlers (IO MCU)](#part-3-ipc-handlers-io-mcu)
7. [Part 4: Configuration (SYS MCU)](#part-4-configuration-sys-mcu)
8. [Part 5: REST API (SYS MCU)](#part-5-rest-api-sys-mcu)
9. [Part 6: Web UI](#part-6-web-ui)
10. [Testing](#testing)

---

## Overview

The Open Reactor Control System uses a **dual-MCU architecture** with a **dual-index device model**:

- **IO MCU (SAME51):** Hardware communication (Modbus, I2C, analog)
- **SYS MCU (RP2040):** Network, storage, UI
- **IPC Protocol:** UART inter-processor communication
- **Dual-Index:**
  - Control Objects (50-69): Device status & setpoints
  - Sensor Objects (70-99): Sensor readings

### Example: Alicat MFC
- Control Index: 52 (setpoint, actual, connected, fault)
- Sensor Indices: 72 (flow), 73 (temp)
- Interface: Modbus RTU, Slave ID 1

---

## Architecture Summary

```
Web UI → REST API → SYS MCU → IPC → IO MCU → Device Hardware

Object Index System:
├── 0-7    : ADC inputs
├── 8-9    : DAC outputs  
├── 10-12  : RTD sensors
├── 13-20  : GPIO pins
├── 21-25  : Digital outputs
├── 26-30  : Motors
├── 31-32  : Power monitors
├── 37-40  : COM ports
├── 50-69  : Device control objects ← Your device control
└── 70-99  : Device sensor objects  ← Your device sensors
```

---

## Integration Checklist

### Phase 1: Device Driver (IO MCU)
- [ ] Create driver header `drv_<interface>_<device>.h`
- [ ] Implement driver source `drv_<interface>_<device>.cpp`
- [ ] Add init() method
- [ ] Add update() state machine
- [ ] Add writeSetpoint() if controllable
- [ ] Add getControlObject() and getSensorObject()
- [ ] Add device type to `objects.h` and `ipc_protocol.h`

### Phase 2: Device Manager (IO MCU)
- [ ] Add factory case in DeviceManager::createDevice()
- [ ] Register control object (index 50-69)
- [ ] Register sensor objects (index 70-99)
- [ ] Create scheduler task for update()
- [ ] Store ManagedDevice entry
- [ ] Add delete case in DeviceManager::deleteDevice()

### Phase 3: IPC Handlers (IO MCU)
- [ ] Add OBJ_T_DEVICE_CONTROL handler in sensor read
- [ ] Add device case in ipc_handle_device_control()
- [ ] Implement DEV_CMD_SET_SETPOINT handler
- [ ] Implement DEV_CMD_RESET_FAULT handler
- [ ] Test with serial monitor

### Phase 4: Configuration (SYS MCU)
- [ ] Add driver definition to DRIVER_TYPES
- [ ] Update ioConfig structures if needed
- [ ] Add driver to Web UI dropdown

### Phase 5: REST API (SYS MCU)
- [ ] Verify /api/devices returns control data
- [ ] Test POST /api/device/{index}/setpoint
- [ ] Test POST /api/device/{index}/fault/reset

### Phase 6: Web UI
- [ ] Add driver to DRIVER_DEFINITIONS with hasSetpoint flag
- [ ] Test device card rendering
- [ ] Test setpoint control
- [ ] Test fault display

---

## Part 1: Device Driver (IO MCU)

See: `DEVICE_DRIVER_TEMPLATE.md` for complete code examples

### Key Files
- `orc-io-mcu/src/drivers/peripheral/drv_<interface>_<device>.h`
- `orc-io-mcu/src/drivers/peripheral/drv_<interface>_<device>.cpp`

### Required Methods

```cpp
class YourDevice {
public:
    YourDevice(InterfaceType* bus, uint8_t address);
    bool init();                              // One-time initialization
    bool update();                            // Periodic state machine
    bool writeSetpoint(float value);          // For controllable devices
    DeviceControl_t* getControlObject();      // Return control object
    SensorData_t* getSensorObject(uint8_t i); // Return sensor i
    uint8_t getSensorCount() const;           // How many sensors
    
private:
    DeviceControl_t _controlObj;              // REQUIRED for all devices
    SensorData_t _sensors[4];                 // Up to 4 sensors
    // ... your state machine variables
};
```

### State Machine Pattern

```cpp
enum State { IDLE, READING, WRITING, WAITING };

bool YourDevice::update() {
    switch (_state) {
        case IDLE:
            if (_setpointPending) {
                _state = WRITING;
            } else {
                _state = READING;
            }
            break;
            
        case READING:
            _bus->readRegisters(_addr, 0, 4);
            _state = WAITING;
            break;
            
        case WRITING:
            _bus->writeRegister(_addr, 10, _pendingSetpoint);
            _setpointPending = false;
            _state = WAITING;
            break;
            
        case WAITING:
            if (timeout) {
                _setFault("Timeout");
                _state = IDLE;
            } else if (response_ready) {
                _parseResponse();
                _state = IDLE;
            }
            break;
    }
    return true;
}
```

### Object Registration
Add to `orc-io-mcu/src/drivers/objects.h`:
```cpp
enum IPC_DeviceType {
    // ... existing ...
    IPC_DEV_YOUR_DEVICE = 10,  // Pick next available number
};
```

---

## Part 2: Device Manager (IO MCU)

See: `DEVICE_MANAGER_INTEGRATION.md` for details

### File: `orc-io-mcu/src/drivers/device_manager.cpp`

Add to `createDevice()`:
```cpp
case IPC_DEV_YOUR_DEVICE: {
    // Get interface (Modbus/I2C/etc)
    InterfaceType* bus = getInterface(config);
    
    // Create instance
    YourDevice* dev = new YourDevice(bus, config->address);
    if (!dev || !dev->init()) {
        delete dev;
        return false;
    }
    
    deviceInstance = dev;
    sensorCount = dev->getSensorCount();
    break;
}
```

Register objects:
```cpp
// Control object (index startIndex - 20)
uint8_t controlIdx = startIndex - 20;
registerObject(controlIdx, OBJ_T_DEVICE_CONTROL, 
               dev->getControlObject(), name, unit);

// Sensor objects (indices startIndex, startIndex+1, ...)
for (uint8_t i = 0; i < sensorCount; i++) {
    registerObject(startIndex + i, OBJ_T_SENSOR,
                  dev->getSensorObject(i), sensorName, unit);
}
```

Create scheduler task:
```cpp
ScheduledTask* task = scheduler.addTask(
    "DEV_72", 2000,  // 2 second interval
    [](void* ctx) { ((YourDevice*)ctx)->update(); },
    deviceInstance
);
task->start();
```

---

## Part 3: IPC Handlers (IO MCU)

See: `IPC_HANDLERS_GUIDE.md` for details

### File: `orc-io-mcu/src/drivers/ipc/ipc_handlers.cpp`

Add include:
```cpp
#include "../peripheral/drv_<your_device>.h"
```

Add sensor read handler:
```cpp
case OBJ_T_DEVICE_CONTROL: {
    DeviceControl_t *ctrl = (DeviceControl_t*)obj;
    data.value = ctrl->setpoint;
    strncpy(data.unit, ctrl->setpointUnit, sizeof(data.unit) - 1);
    
    if (ctrl->actualValue != ctrl->setpoint) {
        data.valueCount = 1;
        data.additionalValues[0] = ctrl->actualValue;
    }
    
    if (ctrl->fault) data.flags |= IPC_SENSOR_FLAG_FAULT;
    if (!ctrl->connected) data.flags |= IPC_SENSOR_FLAG_FAULT;
    break;
}
```

Add control command handler in `ipc_handle_device_control()`:
```cpp
case IPC_DEV_YOUR_DEVICE: {
    YourDevice* dev = (YourDevice*)managedDev->deviceInstance;
    if (!dev) {
        errorCode = CTRL_ERR_DRIVER_FAULT;
        break;
    }
    
    control->setpoint = cmd->setpoint;
    
    if (dev->writeSetpoint(cmd->setpoint)) {
        success = true;
        snprintf(message, sizeof(message), "Setpoint %.2f sent", cmd->setpoint);
    } else {
        errorCode = CTRL_ERR_DRIVER_FAULT;
        strcpy(message, "Failed to queue command");
    }
    break;
}
```

---

## Part 4: Configuration (SYS MCU)

### File: `orc-sys-mcu/src/config/ioConfig.h`

No changes typically needed - uses existing structures.

### File: `orc-sys-mcu/data/devices.js`

Add driver definition:
```javascript
const DRIVER_DEFINITIONS = {
    10: { 
        name: 'Your Device Name',
        interface: 0,  // 0=Modbus, 1=Analogue, 2=Motor
        description: 'Brief description',
        hasSetpoint: true  // true if controllable, false if sensor-only
    }
};
```

---

## Part 5: REST API (SYS MCU)

### File: `orc-sys-mcu/src/utils/ipcManager.cpp`

Already polls control objects (50-69) every 1 second. No changes needed.

### File: `orc-sys-mcu/src/network/network.cpp`

Device endpoints already exist:
- `GET /api/devices` - Returns all devices with control data
- `POST /api/device/{controlIndex}/setpoint` - Set setpoint
- `POST /api/device/{controlIndex}/fault/reset` - Reset fault

The `handleGetDevices()` function automatically includes control data from cache.

---

## Part 6: Web UI

### File: `orc-sys-mcu/data/devices.js`

Add driver with `hasSetpoint` flag (see Part 4).

Device cards automatically render based on `hasSetpoint`:
- `true`: Shows setpoint input, actual value, "Set" button
- `false`: Shows value only (sensor-only device)

Polling is automatic (2 seconds) - no changes needed.

---

## Testing

### 1. IO MCU Serial Monitor
```
[DEV MGR] Created Your Device: index=72, sensors=2
[YOUR_DEV] Initialized successfully
[YOUR_DEV] Reading data...
[YOUR_DEV] Update successful: value=25.3
[DEV CTRL] Set device setpoint: index=52, value=100.0
[YOUR_DEV] Setpoint command queued successfully
```

### 2. SYS MCU Serial Monitor
```
[IPC] Polling objects: 0-40, 50-69, 70-99
[WEB] Device API: Serving control data for device 72
[WEB] POST /api/device/52/setpoint - value=100.0
[IPC] Device setpoint command sent
```

### 3. Web UI
- Open Devices tab
- Device card shows "Connected"
- Setpoint and actual values display
- Enter setpoint, click "Set"
- Values update within 2 seconds

### 4. Verification Steps
1. Device appears in devices list
2. Status shows "Connected"
3. Sensor values update in real-time
4. Setpoint changes reach hardware
5. Fault conditions display correctly
6. Messages show in UI

---

## Quick Reference

### Object Indices
- **Control:** sensorIndex - 20 (e.g., 72 → 52)
- **Sensor:** 70-99 (your startIndex)

### Key Structures
```cpp
DeviceControl_t {
    float setpoint;
    float actualValue;
    char setpointUnit[8];
    bool connected;
    bool fault;
    char message[100];
    uint8_t deviceType;
    uint8_t startSensorIndex;
    uint8_t sensorCount;
}

SensorData_t {
    float value;
    char unit[8];
    char name[40];
    bool fault;
    uint32_t timestamp;
}
```

### IPC Commands
- `IPC_MSG_DEVICE_CONTROL` - Send control command
- `DEV_CMD_SET_SETPOINT` - Set device setpoint
- `DEV_CMD_RESET_FAULT` - Clear fault condition

### REST Endpoints
- `GET /api/devices` - List all devices with control data
- `POST /api/device/{controlIdx}/setpoint` - Set setpoint
- `POST /api/device/{controlIdx}/fault/reset` - Reset fault

---

## Common Patterns

### Sensor-Only Device (pH Probe)
- Has control object (status only)
- `hasSetpoint: false`
- No writeSetpoint() method
- UI shows value only

### Controllable Device (MFC)
- Has control object with setpoint
- `hasSetpoint: true`
- Implements writeSetpoint()
- UI shows setpoint input

### Multi-Sensor Device
- One control object
- Multiple sensor objects (up to 4)
- Each sensor has separate index
- All sensors in Sensors tab

---

## Error Codes

```cpp
CTRL_ERR_NONE = 0x00          // Success
CTRL_ERR_INVALID_INDEX = 0x01 // Control index not found
CTRL_ERR_TYPE_MISMATCH = 0x02 // Wrong device type
CTRL_ERR_INVALID_CMD = 0x03   // Unknown command
CTRL_ERR_OUT_OF_RANGE = 0x04  // Setpoint out of range
CTRL_ERR_NOT_ENABLED = 0x05   // Device not enabled
CTRL_ERR_DRIVER_FAULT = 0x06  // Driver error
CTRL_ERR_TIMEOUT = 0x07       // Communication timeout
```

---

## Troubleshooting

**Device not appearing in UI:**
- Check DeviceManager factory case
- Verify object registration
- Check IPC sensor read handler

**Setpoint not reaching device:**
- Check IPC control command handler
- Verify writeSetpoint() implementation
- Check device state machine

**"DISCONNECTED" status:**
- Check init() return value
- Verify communication in update()
- Check _controlObj.connected flag

**Sensor values not updating:**
- Check scheduler task is running
- Verify update() state machine
- Check sensor object registration

---

## Files Modified Summary

### IO MCU
1. `src/drivers/peripheral/drv_<device>.h` - Driver header
2. `src/drivers/peripheral/drv_<device>.cpp` - Driver implementation
3. `src/drivers/objects.h` - Add device type enum
4. `src/drivers/device_manager.cpp` - Factory pattern
5. `src/drivers/ipc/ipc_handlers.cpp` - IPC handlers
6. `src/drivers/ipc/ipc_protocol.h` - Device type enum

### SYS MCU
7. `data/devices.js` - Driver definition with hasSetpoint

### Both
8. `lib/IPCprotocol/IPCDataStructs.h` - Shared IPC structures

---

**End of Guide**

For detailed code examples, see:
- `DEVICE_DRIVER_TEMPLATE.md` - Complete driver implementation
- `IPC_HANDLERS_GUIDE.md` - IPC protocol details

**Estimated Time:** 2-8 hours depending on device complexity

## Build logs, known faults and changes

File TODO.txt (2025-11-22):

ORC TODO (Bug fixes and improvements as I notice them!):

Modbus:
1. DONE - Better queue management - at the moment an offline device can flood the queue with unresponded requests, limit per device requests in modbus library!
2. More config (1.5 stop bits option, timout value)
3. Show stats - queue size, errors, dropped requests (queue full) etc

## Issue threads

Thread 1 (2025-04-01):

Project checklist

PeakeElectronicInnovation, 2025-04-01:
# Project tasks

Project task list to help keep track of things!

## System Interface Firmware

System interface firmware lives on the RP2040 MCU flash storage and includes the backend C++ firmware, and the frontend html, css and js. The system handles local logging, system configuration, network connection and external interface via MQTT.

### Checklist

High level todo items

- [X] Realtime clock interface and time management
- [X] Status manager and LED driver
- [X] Main supplies voltage monitoring
- [X] Terminal for debug (interactive)

  - [X] Unified and thread-safe terminal access for debug
  - [X] Response for various terminal user requests
- [X] SD card SDIO interface
- [ ] Logging component

  - [X] System event log management
  - [ ] Operational event log management
  - [ ] Sensor recoding management
- [ ] Inter-processor communication

  - [X] IPC structure design
  - [ ] IPC implementation
- [X] W5500 ethernet interface
- [X] Network management
- [ ] Web interface development

  - [ ] Dashboard
    - [ ] Sensor data live
    - [ ] Simple chart with core metrics
    - [ ] Basic controls
  - [ ] System Config
    - [ ] Driver configuration
    - [ ] Port configuration
  - [ ] Sensor Config
    - [ ] Sensor assignment
    - [ ] Calibration
  - [X] Local File Manager
    - [X] Local browser view of SD contents
    - [X] Download small files
  - [ ] System Status
    - [X] Power supplies
    - [X] Clock
    - [ ] Comms - IPC, MQTT and Modbus
    - [X] SD card status and info
  - [X] Settings
    - [X] Time and NTP config
    - [X] IP setting
    - [X] MQTT parameters
- [ ] MQTT interface

  - [ ] Object planning
  - [ ] Implementation and testing

## IO Interface Firmware

IO interface firmware lives on the ATSAME51N20A MCU and includes the core operational programs, object definitions, device drivers and sensor connections. The IO interface handles all of the device connections and control, including on-board interfaces such as motor and stepper controls, high resolution analogue inputs, RTD interfaces, analogue outputs and simple IO, RS485 and RS232 data busses.

### Checklist

High level todo items

- [X] Object structure definitios objects.h
- [ ] On-board hardware interface libraries

  - [X] MCP48FEBxx SPI DAC interface dev
  - [X] MCP346x SPI ΣΔ ADC interface dev
  - [X] MAX31865 SPI RTD interface dev
  - [ ] TMC5130A SPI stepper interface dev
  - [ ] DRV8235 I2C DC motor driver interface dev
  - [ ] INA260 I2C power analyser interface dev
  - [ ] RS485/232 Modbus interface dev
  - [ ] Slow PWM for heating control high current output
- [ ] Driver development - on-board devices

  - [X] Analogue outputs
  - [X] Analogue inputs
  - [X] RTD sensors
  - [ ] GPIO access
  - [ ] Stepper motor
  - [ ] DC motors
  - [ ] Open drain outputs
  - [ ] High current output
  - [ ] Power monitoring
- [ ] Driver development - external devices

  - [ ] Hamilton DO sensor
  - [ ] Hamilton pH sensor
  - [ ] Hamilton Optical Density sensor
  - [ ] Mass flow controller
  - [ ] Backpressure controller
- [ ] Core control program dev

  - [ ] Thermal control component
  - [ ] pH control component
  - [ ] DO control component
  - [ ] Feed control component
  - [ ] Waste control component
  - [ ] Global control component (Run/Pause/Stop?)
  - [ ] Safety manager component
- [ ] Inter-processor communication implementation

tazomatalax, 2025-06-24:
### **System Interface Firmware (RP2040) Status**

| Task                                          | Status                                 | Justification                                                                                                                                                             |
| --------------------------------------------- | -------------------------------------- | ------------------------------------------------------------------------------------------------------------------------------------------------------------------------- |
| **System Components**                         |                                        |                                                                                                                                                                           |
| Realtime clock interface and time management  | ✅ **Completed**                       | `timeManager.cpp` and the `MCP79410` library are fully implemented, including NTP sync logic.                                                                             |
| Status manager and LED driver                 | ✅ **Completed**                       | `statusManager.cpp` uses the `Adafruit_NeoPixel` library to manage the 4 status LEDs based on system state.                                                               |
| Main supplies voltage monitoring              | ✅ **Completed**                       | `powerManager.cpp` reads ADC pins for all main voltages and checks them against defined limits.                                                                           |
| Terminal for debug (interactive)              | ✅ **Completed**                       | `terminalManager.cpp` implements a serial command parser for "reboot", "ip", "status", etc.                                                                               |
| Unified and thread-safe terminal access       | 🟡 **In Progress**                     | A simple `serialLocked` boolean is used as a mutex. It works for this context but is not a robust thread-safe implementation.                                              |
| **Storage Management**                        |                                        |                                                                                                                                                                           |
| SD card SDIO interface                        | ✅ **Completed**                       | `sdManager.cpp` uses the `SdFat` library and successfully initializes the SD card using SDIO (with an SPI fallback).                                                      |
| Logging component & System event log          | ✅ **Completed**                       | The `logger.cpp` and `sdManager.cpp` (`writeLog` function) work together to write timestamped logs to `/logs/system.txt`.                                                  |
| Sensor recording management                   | ❌ **Not Implemented**                 | The `writeSensorData` function in `sdManager.cpp` is a stub and has no implementation.                                                                                    |
| **Communication**                             |                                        |                                                                                                                                                                           |
| Inter-processor communication (IPC)           | ✅ **Completed**                       | The `IPCProtocol` library is included and initialized in `ipcManager.cpp`, setting up the serial port for communication.                                                    |
| IPC structure design                          | 🟡 **In Progress**                     | `IPCDataStructs.h` exists but is a preliminary draft. It needs to be refined and integrated to match the final `objects.h` from the I/O controller.                    |
| W5500 ethernet interface & Network management | ✅ **Completed**                       | `network.cpp` is extensive, handling W5500 initialization, DHCP/static IP, and loading/saving configuration from LittleFS.                                              |
| MQTT interface                                | ❌ **Not Implemented**                 | The API and configuration for MQTT exist, but there is no code that actually connects to a broker or publishes/subscribes to topics.                                      |
| **Web Interface**                             |                                        |                                                                                                                                                                           |
| Web interface development (Server Backend)    | ✅ **Completed**                       | The `WebServer` is fully set up in `network.cpp` and can serve static files from the `data` directory.                                                                  |
| Dashboard, Sensor data, Basic controls        | 🟡 **In Progress**                     | The backend server is running, but the API endpoints return placeholder data. The actual HTML/CSS/JS for a dynamic dashboard is not implemented.                        |
| Local File Manager                            | ✅ **Completed**                       | The API endpoints (`/api/sd/list`, `/api/sd/download`, `/api/sd/view`) are fully implemented and functional in `network.cpp`.                                          |
| System Status page                            | ✅ **Completed**                       | The `/api/system/status` endpoint gathers and returns detailed status information from all relevant managers.                                                             |
| Settings (Time, IP, MQTT)                     | ✅ **Completed**                       | The API endpoints to GET and POST settings for Time/NTP, Network/IP, and MQTT are fully implemented and save to `network_config.json`.                                  |

---
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

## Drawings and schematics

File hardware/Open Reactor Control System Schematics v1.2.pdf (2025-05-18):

## Polarity and transient protection

## +20V Aalogue output supply

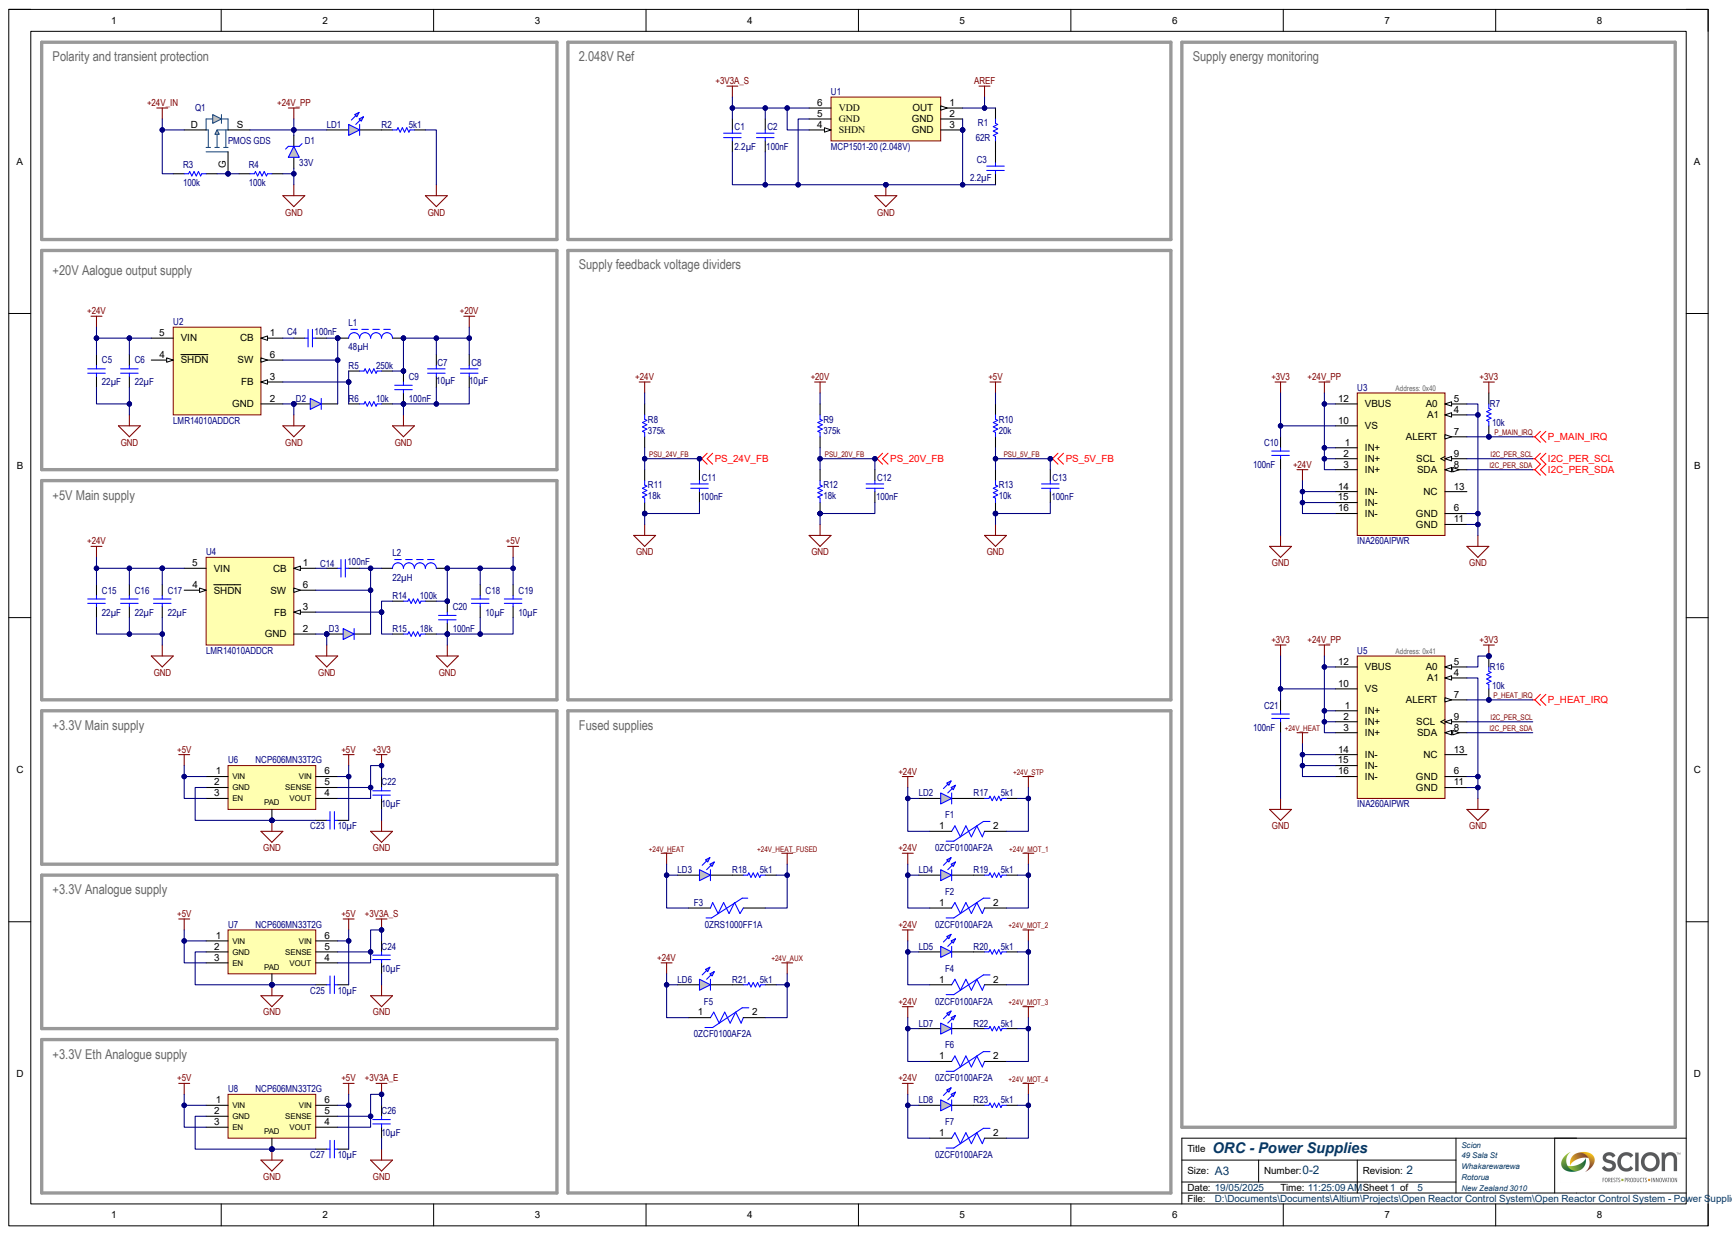
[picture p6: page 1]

Supply feedback voltage dividers

ORC - Power Supplies
Title
D:\Documents\Documents\Altium\Projects\Open Reactor Control System\Open Reactor Control System - Power Supplies.SchDoc

## System Interface Microcontroller

Ethernet interface | 10k R²⁸ ¹⁰k R²⁹

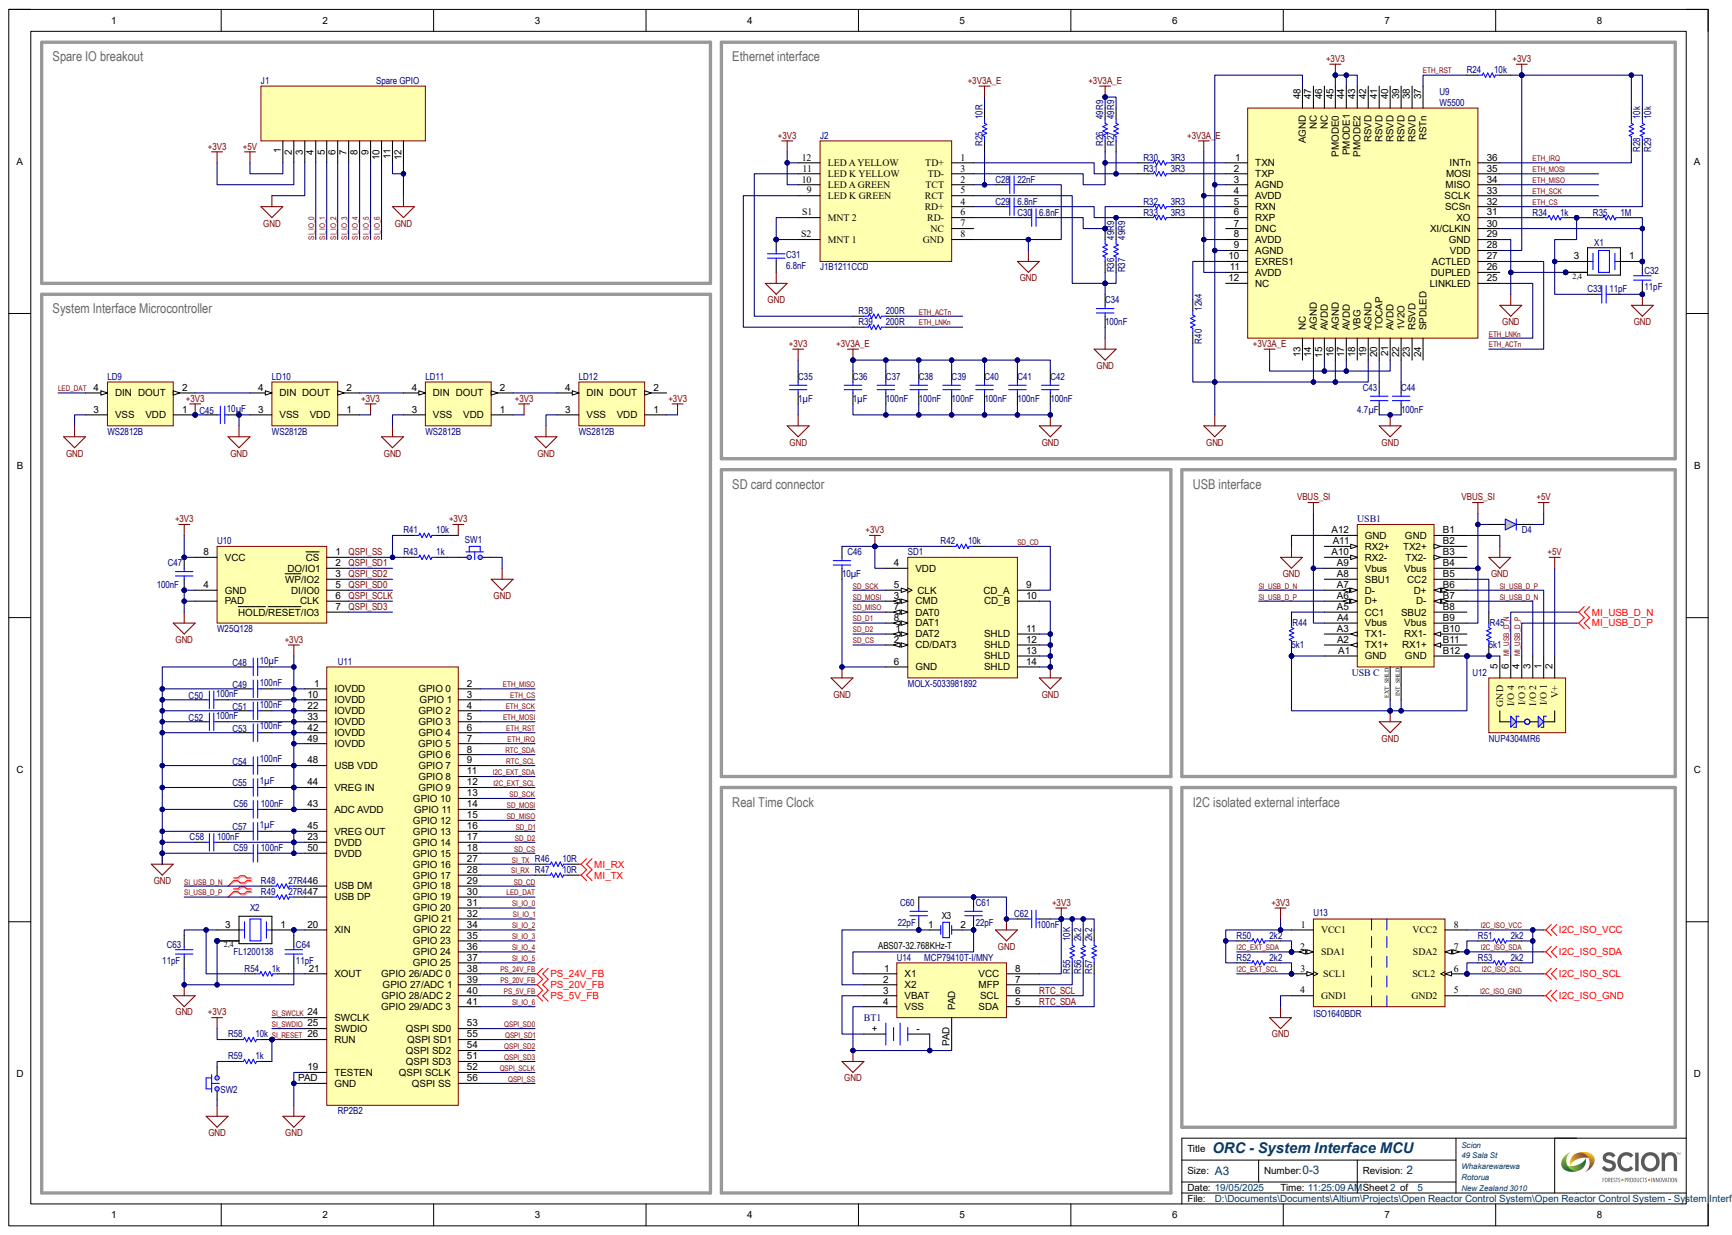
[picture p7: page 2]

R33 3R3 ⁴⁹R⁹ R²⁶ ⁴⁹R⁹ R²⁷ 49R⁹ R³⁶ ⁴⁹R⁹ R³⁷

C50 | 100nF | | IOVDD 10

C52 | 100nF | | IOVDD 33

C51 | 100nF | IOVDD 22

ORC - System Interface MCU

D:\Documents\Documents\Altium\Projects\Open Reactor Control System\Open Reactor Control System - System Interface MCU.SchDoc

## Machine Interface Microcontroller

## RS485 interfaces

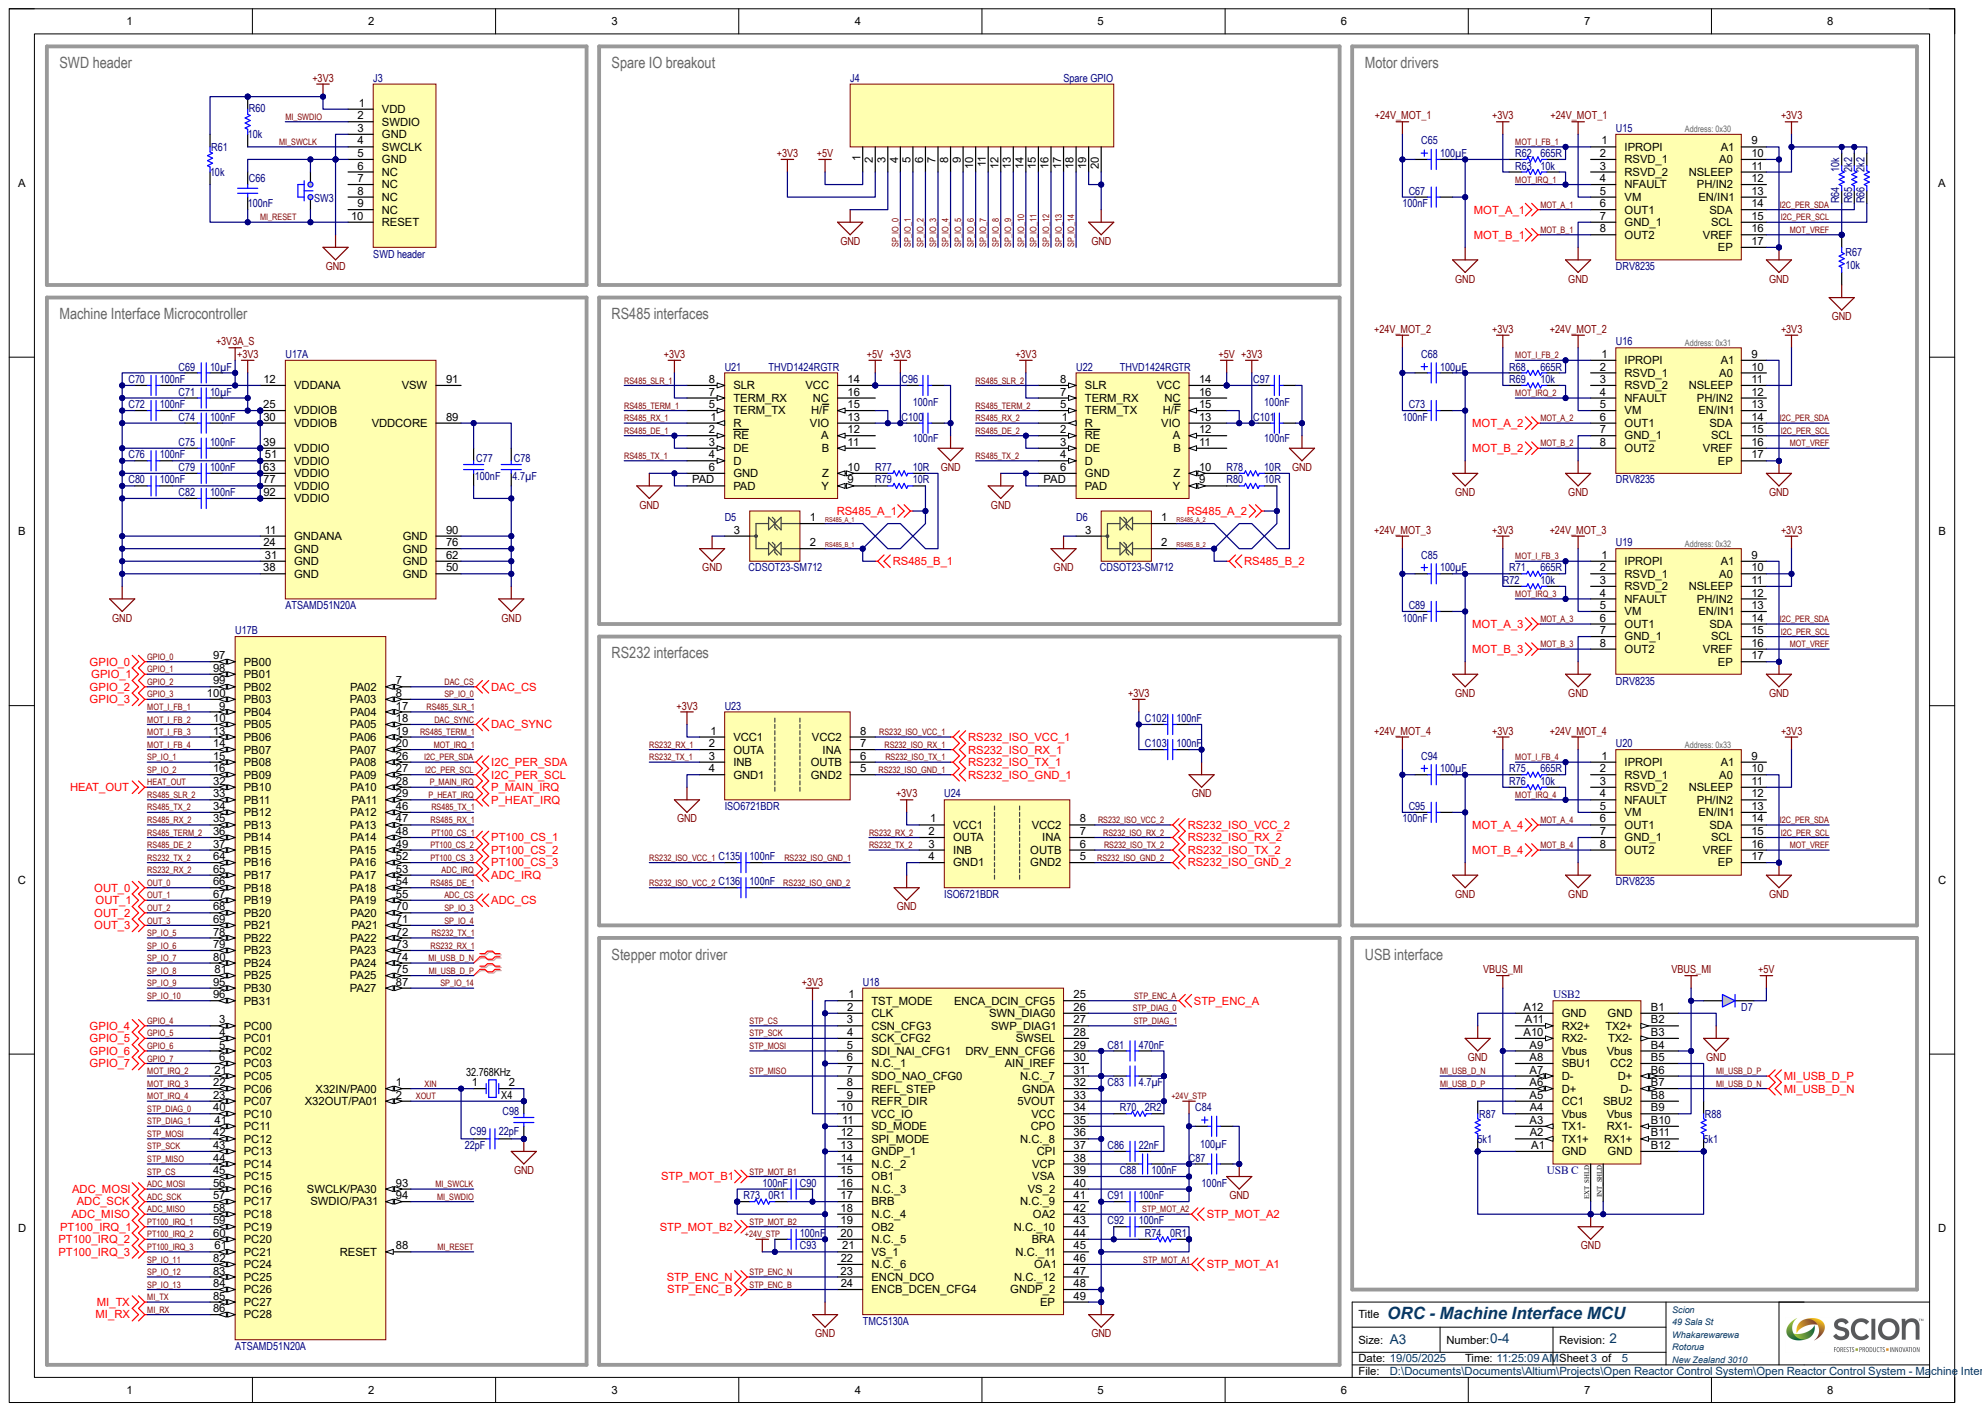
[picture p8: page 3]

ORC - Machine Interface MCU

D:\Documents\Documents\Altium\Projects\Open Reactor Control System\Open Reactor Control System - Machine Interface MCU.SchDoc

## PT100 interface

## 4-20mA / 0-10V Analogue Inputs

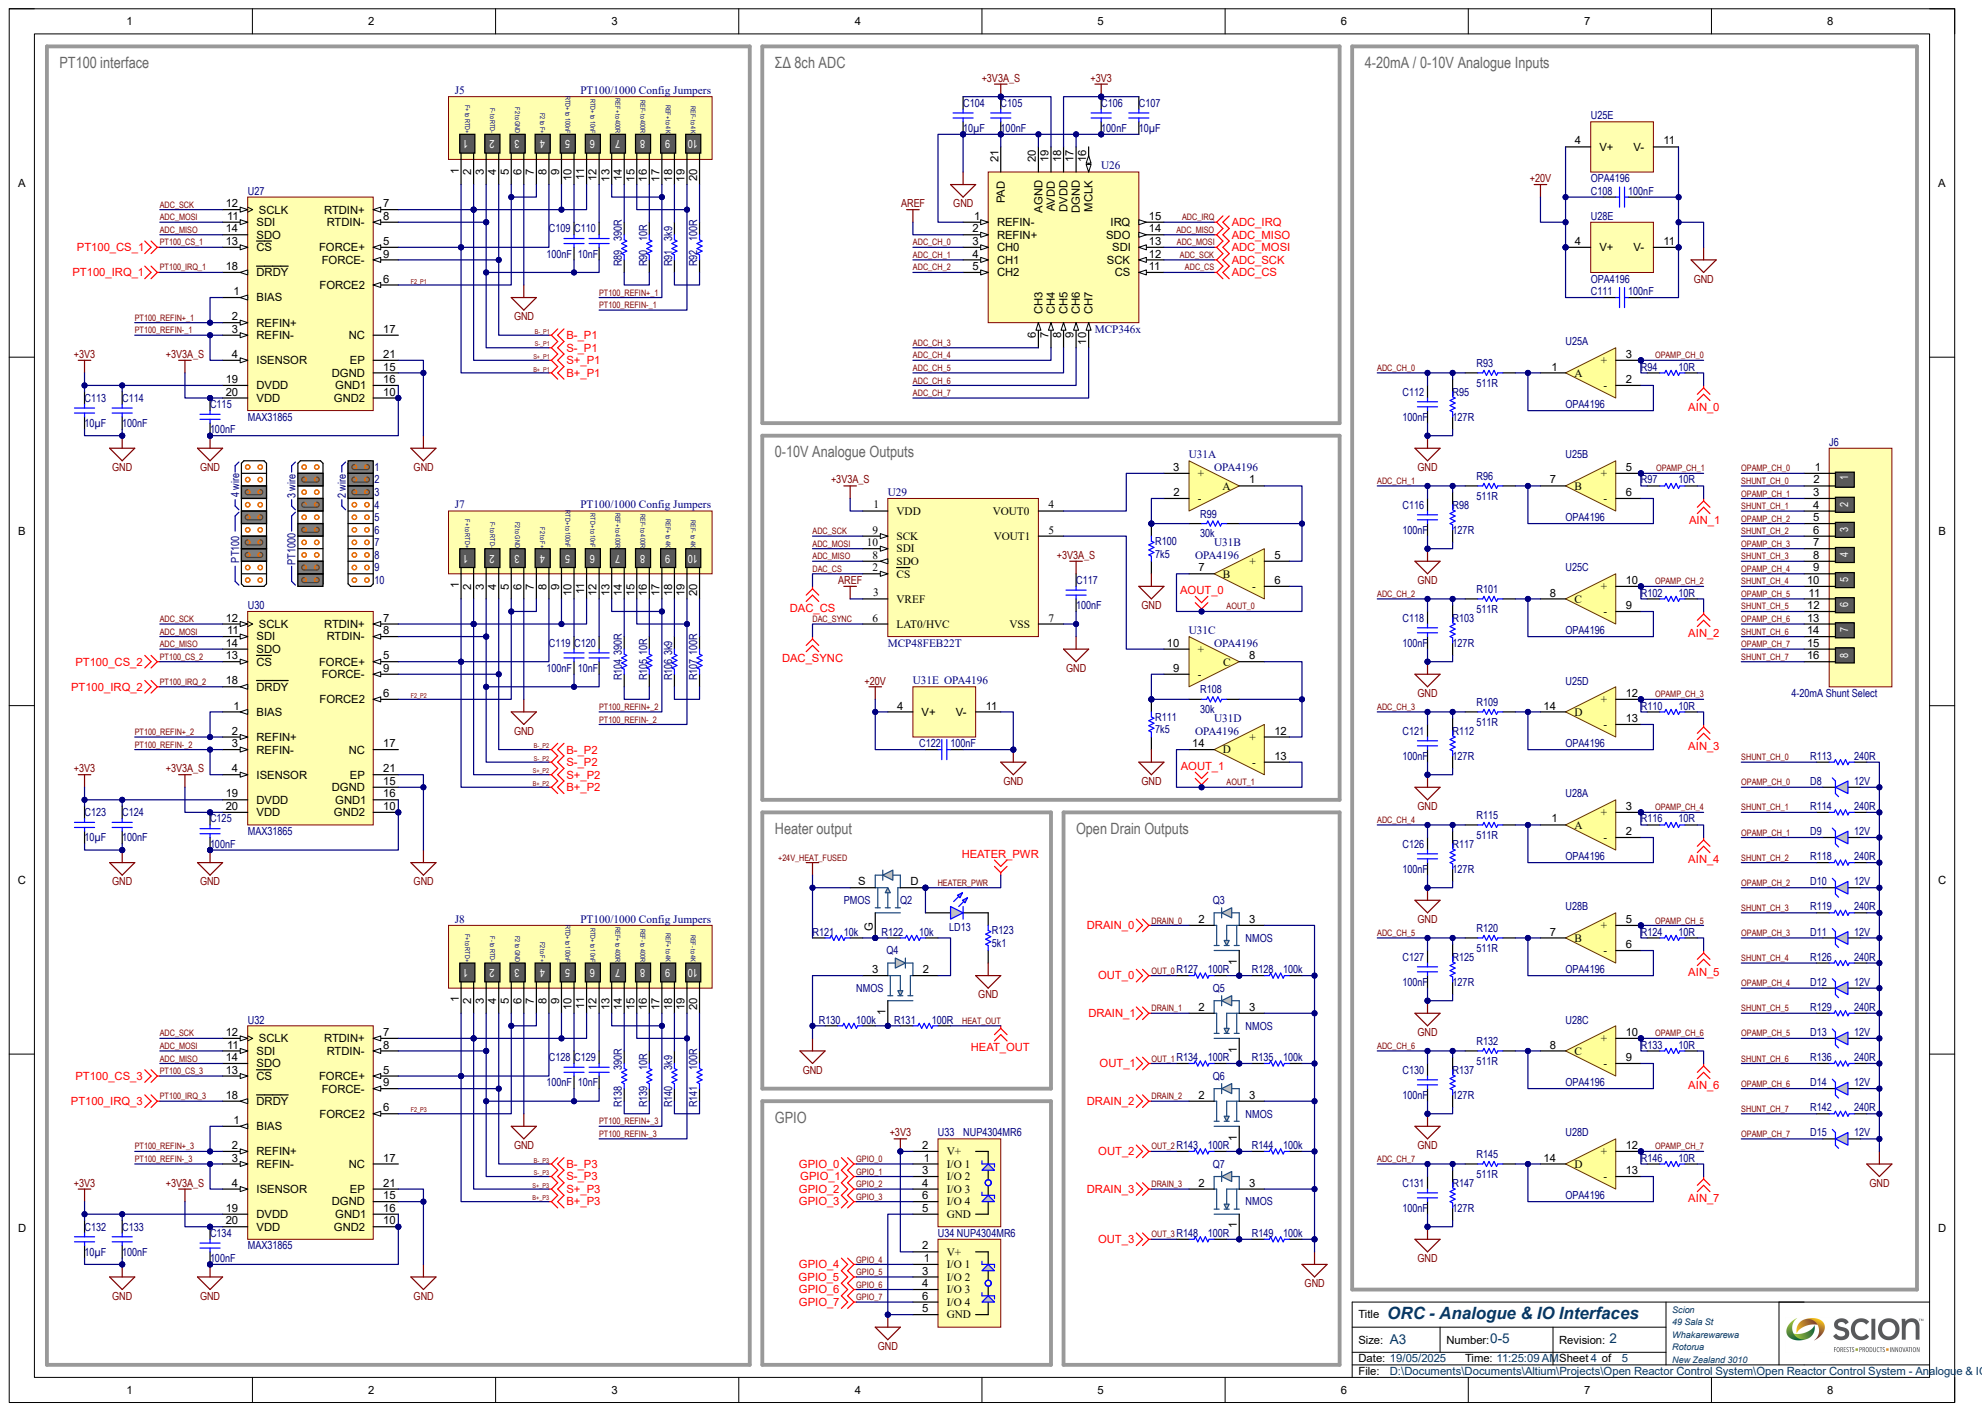
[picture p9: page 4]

ORC - Analogue & IO Interfaces

D:\Documents\Documents\Altium\Projects\Open Reactor Control System\Open Reactor Control System - Analogue & IO Interfaces.SchDoc

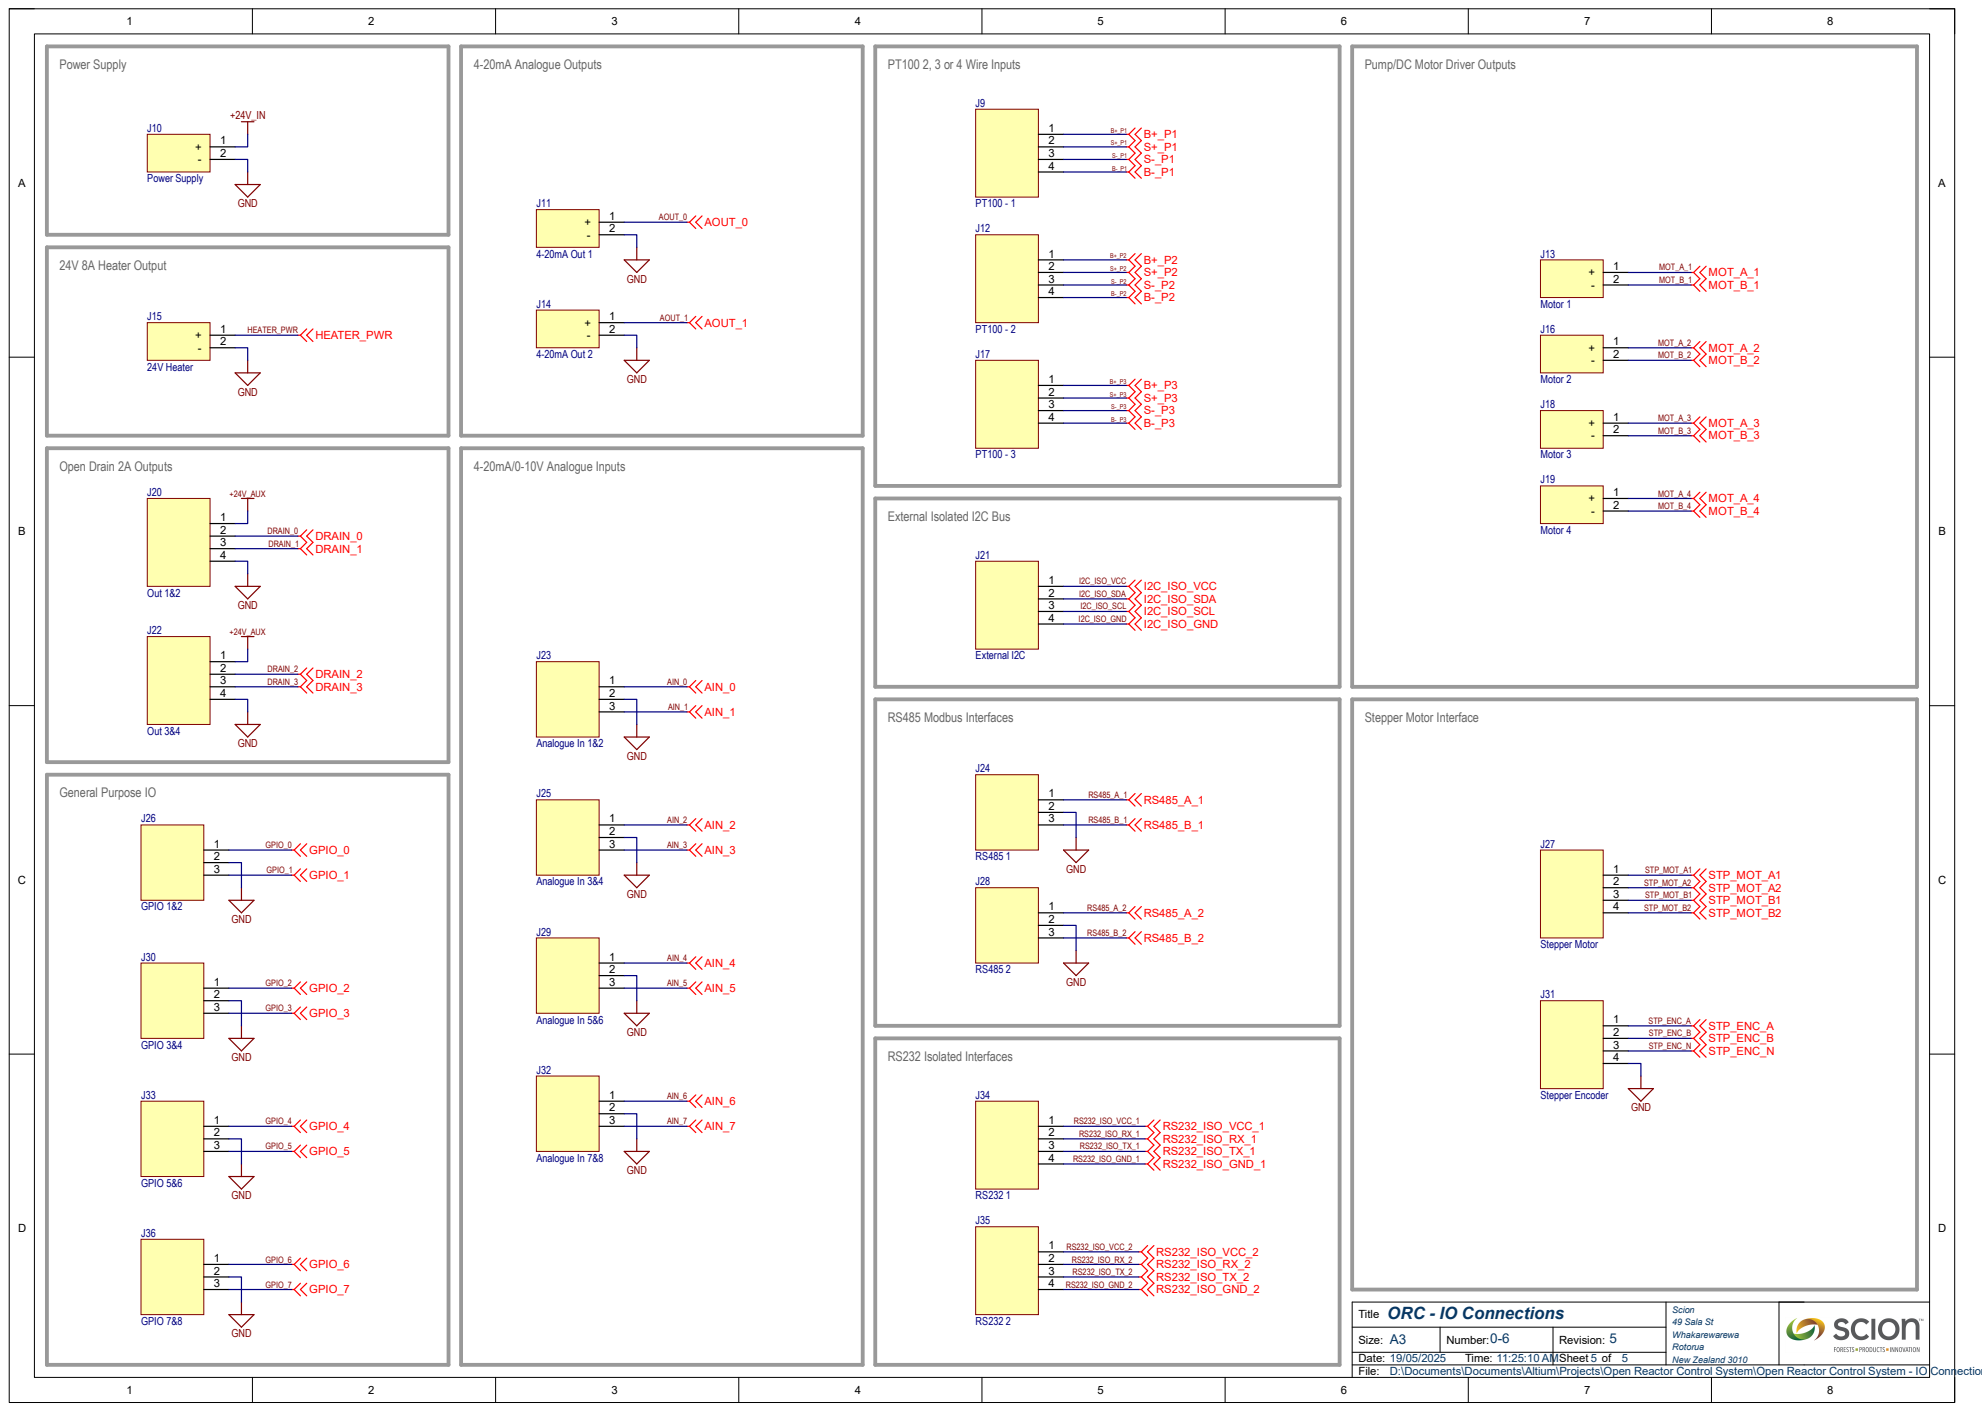
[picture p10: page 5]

Pump/DC Motor Driver Outputs

D:\Documents\Documents\Altium\Projects\Open Reactor Control System\Open Reactor Control System - IO Connections.SchDoc

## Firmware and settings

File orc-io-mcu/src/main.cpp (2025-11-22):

#include "sys_init.h"

// Debug functions and variables can be added here --------------------------->

void modbusDebugMonitor() {
  Serial.println("Modbus Stats:");
  // Monitor Modbus queues for debugging
  uint8_t slaveQueued[8] = {0};
  uint8_t totalQueued = 0;
  for (int i = 0; i < 8; i++) {
    slaveQueued[i] = modbusDriver[2].modbus.getSlaveQueueCount(i+1);
    if (slaveQueued[i] > 0) {
      Serial.printf("  Slave ID %d: %d requests queued\n", i+1, slaveQueued[i]);
    }
  }
  totalQueued = modbusDriver[2].modbus.getQueueCount();
  Serial.printf("Total requests queued: %d\n", totalQueued);
}

void debugTaskCallback() {
  // Add calls to debug functions here
  //modbusDebugMonitor();
}

// <---------------------------------------------------------------------------

void setupCSpins(void) {
  pinMode(PIN_ADC_CS, OUTPUT);
  pinMode(PIN_DAC_CS, OUTPUT);
  pinMode(PIN_PT100_CS_1, OUTPUT);
  pinMode(PIN_PT100_CS_2, OUTPUT);
  pinMode(PIN_PT100_CS_3, OUTPUT);

  digitalWrite(PIN_ADC_CS, HIGH);
  digitalWrite(PIN_DAC_CS, HIGH);
  digitalWrite(PIN_PT100_CS_1, HIGH);
  digitalWrite(PIN_PT100_CS_2, HIGH);
  digitalWrite(PIN_PT100_CS_3, HIGH);
}

void setup() {
  uint32_t startTime = millis();
  asm(".global _printf_float");
  // Init serial port:
  Serial.begin(115200);
  setupCSpins();    // Initialise CS pins so that devices can be initialised
  
  uint32_t serialWaitTime = 5000;
  while (!Serial) {
    delay(1);
    if (millis() - startTime > serialWaitTime) break;
  }

  Serial.println("Starting IO MCU (ATSAME51N20A)...");

  Serial.print("Initialising ADC interface... ");
  ADC_init();
  Serial.printf("%s\n", adcDriver.message);

  // PT100 setup testing
  Serial.print("Initialising RTD interface... ");
  if (!init_rtdDriver()) {
    Serial.println("Failed to initialise RTD driver.");
  } else {
    Serial.println("RTD driver initialised.");
  }

  // DAC setup testing
  Serial.print("Initialising DAC interface... ");
  if (!DAC_init()) {
    Serial.print("Failed to initialise DAC driver: ");
    Serial.printf("%s, Result Ch1: %s, Result Ch2: %s\n", dacDriver.message, dacDriver.outputObj[0]->message, dacDriver.outputObj[1]->message);
  } else {
    Serial.println("DAC driver initialised.");
  }

  // TMC5130 stepper setup testing
  Serial.print("Initialising TMC5130 stepper driver... ");
  if (!stepper_init()) {
    Serial.print("Failed to initialise TMC5130 driver: ");
    if (stepperDevice.fault) Serial.printf("Fault: %s\n", stepperDevice.message);
  } else {
    Serial.println("TMC5130 stepper driver initialised.");
  }

  // DRV8235 motor driver initialisation
  Serial.print("Initialising DRV8235 motor drivers... ");
  if (!motor_init()) {
    Serial.print("Failed to initialise DRV8235 motor drivers: ");
    for (int i = 0; i < 4; i++) {
      if (motorDevice[i].fault) Serial.printf("Motor %d fault: %s\n", i+1, motorDevice[i].message);
    }
  } else {
    Serial.println("DRV8235 motor drivers initialised.");
  }

  // INA260 power sensor initialisation
  Serial.print("Initialising INA260 power sensors... ");
  if (!pwrSensor_init()) {
    Serial.print("Failed to initialise INA260 power sensors: ");
    for (int i = 0; i < 2; i++) {
      if (pwr_energy[i].fault) Serial.printf("Power sensor %d fault: %s\n", i+1, pwr_energy[i].message);
    }
  } else {
    Serial.println("INA260 power sensors initialised.");
  }

  // Outputs initialisation
  Serial.print("Initialising outputs... ");
  output_init();
  Serial.println("Outputs initialised.");

  Serial.println("Setting output initial states");
  for (int i = 0; i < 4; i++) {
    outputDriver.outputObj[i]->pwmEnabled = false;
    outputDriver.outputObj[i]->pwmDuty = 0;
    outputDriver.outputObj[i]->state = false;
  }

  Serial.println("Setting heater output initial state");
  heaterOutput[0].pwmEnabled = false;
  heaterOutput[0].pwmDuty = 0;
  heaterOutput[0].state = false;

  Serial.print("Initialising GPIO pins... ");
  gpio_init();
  Serial.println("GPIO pins initialised.");

  Serial.print("Starting Modbus interface... ");
  if (!modbus_init()) {
    Serial.print("Failed to initialise Modbus driver: ");
    for (int i = 0; i < 4; i++) {
      if (modbusPort[i].fault) Serial.printf("Port %i Fault: %s\n", i+1, modbusPort[i].message);
    }
  } else {
    Serial.println("Modbus interface started.");
  }

  Serial.print("Starting IPC interface... ");
  if (!ipc_init()) {
    Serial.println("Failed to initialise IPC driver.");
  } else {
    Serial.println("IPC driver initialised at 2 Mbps.");
  }

  Serial.print("Initialising Device Manager... ");
  if (!DeviceManager::init()) {
    Serial.println("Failed to initialise Device Manager.");
  } else {
    Serial.println("Device Manager initialised");
  }

  Serial.print("Initialising Controller Manager... ");
  if (!ControllerManager::init()) {
    Serial.println("Failed to initialise Controller Manager.");
  } else {
    Serial.println("Controller Manager initialised");
  }

  // Count all registered objects for IPC index sync
  Serial.print("Counting registered objects... ");
  int objectCount = updateObjectCount();
  Serial.printf("Found %d objects ready for IPC\n", objectCount);

  Serial.print("Adding tasks to scheduler... ");
  analog_input_task = tasks.addTask(ADC_update, 10, true, false);
  analog_output_task = tasks.addTask(DAC_update, 100, true, false);
  output_task = tasks.addTask(output_update, 100, true, false);
  gpio_task = tasks.addTask(gpio_update, 100, true, true);
  modbus_task = tasks.addTask(modbus_manage, 10, true, true);
  ipc_task = tasks.addTask(ipc_update, 5, true, true);
  RTDsensor_task = tasks.addTask(RTD_manage, 200, true, false);
  stepper_task = tasks.addTask(stepper_update, 1000, true, false);
  motor_task = tasks.addTask(motor_update, 10, true, false);
  pwrSensor_task = tasks.addTask(pwrSensor_update, 1000, true, false);

  // Debug task
  DEBUG_TASK = tasks.addTask(debugTaskCallback, 2000, true, false);
  
  Serial.println("Setup done, hardware ready, waiting for System MCU to initialise...");
  
  // Signal to IPC driver that all hardware is ready
  // This enables periodic HELLO broadcasting for robust startup
  ipc_setHardwareReady();
}

void loop() {
  tasks.update();
}

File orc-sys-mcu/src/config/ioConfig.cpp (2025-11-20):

#include "ioConfig.h"
#include "../sys_init.h"  // For ipc global instance

// Global configuration instance
IOConfig ioConfig;

/**
 * @brief Set default configuration values for all IO objects
 */
void setDefaultIOConfig() {
    log(LOG_INFO, false, "Setting default IO configuration\n");
    
    // Set magic number and version
    ioConfig.magicNumber = IO_CONFIG_MAGIC_NUMBER;
    ioConfig.version = IO_CONFIG_VERSION;
    
    // ========================================================================
    // ADC Inputs (Indices 0-7)
    // ========================================================================
    for (int i = 0; i < MAX_ADC_INPUTS; i++) {
        snprintf(ioConfig.adcInputs[i].name, sizeof(ioConfig.adcInputs[i].name), 
                 "Analog Input %d", i + 1);
        strcpy(ioConfig.adcInputs[i].unit, "mV");
        ioConfig.adcInputs[i].cal.scale = 1.0;
        ioConfig.adcInputs[i].cal.offset = 0.0;
        ioConfig.adcInputs[i].enabled = true;
        ioConfig.adcInputs[i].showOnDashboard = false;
    }
    
    // ========================================================================
    // DAC Outputs (Indices 8-9)
    // ========================================================================
    for (int i = 0; i < MAX_DAC_OUTPUTS; i++) {
        snprintf(ioConfig.dacOutputs[i].name, sizeof(ioConfig.dacOutputs[i].name), 
                 "Analog Output %d", i + 1);
        strcpy(ioConfig.dacOutputs[i].unit, "mV");
        ioConfig.dacOutputs[i].cal.scale = 1.0;
        ioConfig.dacOutputs[i].cal.offset = 0.0;
        ioConfig.dacOutputs[i].enabled = true;
        ioConfig.dacOutputs[i].showOnDashboard = false;
    }
    
    // ========================================================================
    // RTD Temperature Sensors (Indices 10-12)
    // ========================================================================
    for (int i = 0; i < MAX_RTD_SENSORS; i++) {
        snprintf(ioConfig.rtdSensors[i].name, sizeof(ioConfig.rtdSensors[i].name), 
                 "RTD Temperature %d", i + 1);
        strcpy(ioConfig.rtdSensors[i].unit, "C");
        ioConfig.rtdSensors[i].cal.scale = 1.0;
        ioConfig.rtdSensors[i].cal.offset = 0.0;
        ioConfig.rtdSensors[i].wireConfig = 3;      // 3-wire by default
        ioConfig.rtdSensors[i].nominalOhms = 100;   // PT100 by default
        ioConfig.rtdSensors[i].enabled = true;
        ioConfig.rtdSensors[i].showOnDashboard = false;
    }
    
    // ========================================================================
    // Digital Inputs (Indices 13-20)
    // ========================================================================
    for (int i = 0; i < MAX_GPIO; i++) {
        snprintf(ioConfig.gpio[i].name, sizeof(ioConfig.gpio[i].name), 
                 "Input %d", i + 1);  // Label as Input 1-8 to match board
        ioConfig.gpio[i].pullMode = GPIO_PULL_UP;  // Default to pull-up
        ioConfig.gpio[i].enabled = true;
        ioConfig.gpio[i].showOnDashboard = false;
    }
    
    // ========================================================================
    // Digital Outputs (Indices 21-25: Open Drain 1-4, High Current)
    // ========================================================================
    const char* outputNames[] = {"Output 1", "Output 2", "Output 3", "Output 4", "Heater Output"};
    for (int i = 0; i < MAX_DIGITAL_OUTPUTS; i++) {
        strlcpy(ioConfig.digitalOutputs[i].name, outputNames[i], 
                sizeof(ioConfig.digitalOutputs[i].name));
        ioConfig.digitalOutputs[i].mode = OUTPUT_MODE_ON_OFF;
        ioConfig.digitalOutputs[i].enabled = true;
        ioConfig.digitalOutputs[i].showOnDashboard = false;
    }
    
    // ========================================================================
    // Stepper Motor (Index 26)
    // ========================================================================
    strlcpy(ioConfig.stepperMotor.name, "Stepper Motor", 
            sizeof(ioConfig.stepperMotor.name));
    ioConfig.stepperMotor.stepsPerRev = 200;
    ioConfig.stepperMotor.maxRPM = 500;
    ioConfig.stepperMotor.holdCurrent_mA = 50;   // Safe default: 50mA hold current
    ioConfig.stepperMotor.runCurrent_mA = 100;   // Safe default: 100mA run current
    ioConfig.stepperMotor.acceleration = 100;
    ioConfig.stepperMotor.invertDirection = false;
    ioConfig.stepperMotor.enabled = true;
    ioConfig.stepperMotor.showOnDashboard = false;
    
    // TMC5130 advanced features defaults
    ioConfig.stepperMotor.stealthChopEnabled = false;     // Default disabled
    ioConfig.stepperMotor.coolStepEnabled = false;        // Default disabled
    ioConfig.stepperMotor.fullStepEnabled = false;        // Default disabled
    ioConfig.stepperMotor.stealthChopMaxRPM = 100.0;      // Default threshold
    ioConfig.stepperMotor.coolStepMinRPM = 200.0;         // Default threshold
    ioConfig.stepperMotor.fullStepMinRPM = 300.0;         // Default threshold
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

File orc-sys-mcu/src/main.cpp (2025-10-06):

#include "sys_init.h"

// Timing variables for cooperative multitasking
unsigned long lastSDManagerTime = 0;
unsigned long lastLEDManagerTime = 0;
unsigned long lastTimeManagerTime = 0;
unsigned long lastPowerManagerTime = 0;
unsigned long lastTerminalTime = 0;
unsigned long lastNetworkTime = 0;
unsigned long lastIpcManagerTime = 0;

void setup() // Eth interface (keep hardware-specific initialization on core 0)
{
  log(LOG_DEBUG, false, "[Core0] setup() start\n");
  init_core0(); // All core 0 initialisation in this function

  log(LOG_INFO, false, "Core 0 setup complete\n");
  core0setupComplete = true;
  while (!core1setupComplete) delay(100);
  if (networkConfig.ntpEnabled) handleNTPUpdates(true);
  log(LOG_INFO, false, "<---System initialisation complete --->\n\n");
}

void setup1()
{
  while (!serialReady) delay(100);
  log(LOG_INFO, false, "Core 1 setup started\n");
  init_core1(); // All core 1 initialisation in this function
  log(LOG_INFO, false, "Core 1 setup complete\n");
  core1setupComplete = true;
  while (!core0setupComplete) delay(100);
}

// Core 0 - network and coordination
void loop()
{
  manage_core0();
}

// Core 1 - all other subsystems
void loop1() {
  manage_core1();
}

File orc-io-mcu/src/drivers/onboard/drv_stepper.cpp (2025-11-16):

#include "drv_stepper.h"

#define STEPPER_DEBUG 0

StepperDriver_t stepperDriver;
StepperDevice_t stepperDevice;

bool stepper_init(void) {
    stepperDriver.stepper = new TMC5130(PIN_STP_CS, &SPI1);
    stepperDriver.device = &stepperDevice;
    stepperDriver.ready = false;
    stepperDriver.fault = false;
    
    // Initialize device object
    stepperDevice.rpm = 0;
    stepperDevice.running = false;
    stepperDevice.enabled = false;
    strcpy(stepperDevice.unit, "rpm");
    stepperDevice.fault = false;
    stepperDevice.newMessage = false;
    stepperDevice.message[0] = '\0';
    
    // Add to object index (fixed index 26)
    objIndex[26].type = OBJ_T_STEPPER_MOTOR;
    objIndex[26].obj = &stepperDevice;
    strcpy(objIndex[26].name, "Stepper Motor");
    objIndex[26].valid = true;

    if (!stepperDriver.stepper->begin()) {
        stepperDriver.fault = true;
        stepperDriver.newMessage = true;
        strcpy(stepperDriver.message, "Stepper initialisation failed");
        
        // Propagate fault to device object
        stepperDevice.fault = true;
        stepperDevice.newMessage = true;
        strcpy(stepperDevice.message, stepperDriver.message);
        
        return false;
    }
    stepperDriver.stepper->setRPM(0.0);
    stepperDriver.stepper->stop();

    return true;
}

void stepper_update(void) {
    stepper_update_cfg(false);
}

bool stepper_update_cfg(bool setParams) {
    static uint32_t numUpdateFail = 0;
    if (!stepperDriver.stepper->updateStatus()) {   // Note: updateStatus() fails if the stepper velocity controller is ramping, handle gracefully instead of returning false
        numUpdateFail++;
        if (numUpdateFail > 10) {
            stepperDriver.fault = true;
            stepperDriver.newMessage = true;
            strcpy(stepperDriver.message, "Stepper status update failed");
            #if STEPPER_DEBUG
                Serial.printf("[STP FAULT] - %s\n", stepperDriver.message);
            #endif
        
            // Propagate fault to device object
            stepperDevice.fault = true;
            stepperDevice.newMessage = true;
            strcpy(stepperDevice.message, stepperDriver.message);
        }
    } else {
        numUpdateFail = 0;
        if (stepperDriver.stepper->status.overTemp) {
            stepperDriver.fault = true;
            stepperDriver.newMessage = true;
            strcpy(stepperDriver.message, "Stepper over temperature");
        } else if (stepperDriver.stepper->status.stall) {
            stepperDriver.fault = true;
            stepperDriver.newMessage = true;
            strcpy(stepperDriver.message, "Stepper stall detected");
        }
        if (stepperDriver.fault) {
            // Propagate fault to device object
            stepperDevice.fault = true;
            stepperDevice.newMessage = true;
            strcpy(stepperDevice.message, stepperDriver.message);
            #if STEPPER_DEBUG
                Serial.printf("[STP FAULT] - %s\n", stepperDriver.message);
            #endif
        }
    }
    if (setParams) {
        // Update stepper parameters
        if (!stepperDriver.stepper->setMaxRPM(stepperDevice.maxRPM)) {
            stepperDriver.fault = true;
            stepperDriver.newMessage = true;
            strcpy(stepperDriver.message, "Stepper max RPM not set");
            
            // Propagate fault
            stepperDevice.fault = true;
            stepperDevice.newMessage = true;
            strcpy(stepperDevice.message, stepperDriver.message);
            #if STEPPER_DEBUG
                Serial.printf("[STP FAULT] - %s\n", stepperDriver.message);
            #endif
            return false;
        }
        if (!stepperDriver.stepper->setStepsPerRev(stepperDevice.stepsPerRev)) {
            stepperDriver.fault = true;
            stepperDriver.newMessage = true;
            strcpy(stepperDriver.message, "Stepper steps per rev not set");
            
            // Propagate fault
            stepperDevice.fault = true;
            stepperDevice.newMessage = true;
            strcpy(stepperDevice.message, stepperDriver.message);
            #if STEPPER_DEBUG
                Serial.printf("[STP FAULT] - %s\n", stepperDriver.message);
            #endif
            return false;
        }
        if (!stepperDriver.stepper->invertDirection(stepperDevice.inverted)) {
            stepperDriver.fault = true;
            stepperDriver.newMessage = true;
            strcpy(stepperDriver.message, "Stepper inversion not set");
            
            // Propagate fault
            stepperDevice.fault = true;
            stepperDevice.newMessage = true;
            strcpy(stepperDevice.message, stepperDriver.message);
            #if STEPPER_DEBUG
                Serial.printf("[STP FAULT] - %s\n", stepperDriver.message);
            #endif
            return false;
        }
        if (!stepperDriver.stepper->setDirection(stepperDevice.direction)) {
            stepperDriver.fault = true;
            stepperDriver.newMessage = true;
            strcpy(stepperDriver.message, "Stepper direction not set");
            
            // Propagate fault
            stepperDevice.fault = true;
            stepperDevice.newMessage = true;
            strcpy(stepperDevice.message, stepperDriver.message);
            #if STEPPER_DEBUG
                Serial.printf("[STP FAULT] - %s\n", stepperDriver.message);
            #endif
            return false;
        }
        if (!stepperDriver.stepper->setAcceleration(stepperDevice.acceleration)) {
            stepperDriver.fault = true;
            stepperDriver.newMessage = true;
            strcpy(stepperDriver.message, "Stepper acceleration not set");
            
            // Propagate fault
            stepperDevice.fault = true;
            stepperDevice.newMessage = true;
            strcpy(stepperDevice.message, stepperDriver.message);
            #if STEPPER_DEBUG
                Serial.printf("[STP FAULT] - %s\n", stepperDriver.message);
            #endif
            return false;
        }
        if (!stepperDriver.stepper->setIhold(stepperDevice.holdCurrent)) {
            stepperDriver.fault = true;
            stepperDriver.newMessage = true;
            strcpy(stepperDriver.message, "Stepper hold current not set");
            
            // Propagate fault
            stepperDevice.fault = true;
            stepperDevice.newMessage = true;
            strcpy(stepperDevice.message, stepperDriver.message);
            #if STEPPER_DEBUG
                Serial.printf("[STP FAULT] - %s\n", stepperDriver.message);
            #endif
            return false;
        }
        if (!stepperDriver.stepper->setIrun(stepperDevice.runCurrent)) {
            stepperDriver.fault = true;
            stepperDriver.newMessage = true;
            strcpy(stepperDriver.message, "Stepper run current not set");
            
            // Propagate fault
            stepperDevice.fault = true;
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

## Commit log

2025-01-22 Added hardware, added MQTT config
    [Open Reactor Control System - Analogue & IO Interfaces.SchDoc, Open Reactor Control System - IO Connections.SchDoc, Open Reactor Control System - Machine Inter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]
2025-01-24 Added thread safe debug serial method
2025-01-24 Added thread safe global LED colour set method
2025-01-24 Added basic voltage monitoring, relocated hardware files
    [Open Reactor Control System - Analogue & IO Interfaces.SchDoc, Open Reactor Control System - IO Connections.SchDoc, Open Reactor Control System - Machine Inter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]
2025-01-24 Added warning status to system LED for voltage out of range
2025-01-27 Removed NTP sync task, called by main loop now. Added RTC set check and error handling.
    [main.cpp]
2025-01-28 Added System page to web app, Voltage monitorinng now displayed in web
2025-01-28 Terminal handler bug fix - buffer overrun
    [main.cpp]
2025-02-04 Fixed DHCP renew on re-plug issue, added IPCprotocol
    [main.cpp]
2025-02-18 Organised pin definitions
2025-02-18 Added README and board pics
2025-03-10 Improved web responses, FS bug fixes
    [network.cpp]
2025-03-10 SDIO pin definition error fix
    [pins.h]
2025-03-11 Small tidy up to power exception logging
2025-03-12 Moved LED colour changes to ledManager
2025-03-17 Added NTP updates back in, retry for SDIO init on mount
2025-03-19 Created first driver, sensor and control objects.
2025-03-24 Added DAC driver components, added calibration components
2025-03-26 Added ADC driver
2025-04-08 TMC5130 lib and driver created
2025-05-15 Created DRV8235 motor driver linterface library
2025-05-16 Created BDC motor driver
2025-05-16 Improved BDC motor eror logging
2025-05-18 Updated hardware to revision 2
    [Open Reactor Control System - Analogue & IO Interfaces.SchDoc, Open Reactor Control System - IO Connections.SchDoc, Open Reactor Control System - Machine Inter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]
2025-05-19 Created INA260 power sensor device library
2025-05-21 Completed power sensor driver, creted object index tagged union system
2025-05-29 Created outputs driver
2025-05-29 Completed heater output driver slow PWM implementation
2025-05-30 Completed main GPIO and expansion GPIO driver
2025-06-09 Scheduler variable init bug fix
    [main.cpp, pins.h]
2025-08-11 feat(network, controls): Implement robust MQTT data flow, topic registry, and control API integration
    - Add PubSubClient to platformio.ini for MQTT support
    - Refactor mqttManager for resilient connection (LWT, keepalive, reconnect, credentials)
    - Publish individual and consolidated sensor/system status data with ISO8601 timestamps
    - Use device-scoped topic prefixes (MAC or config override)
    - Introduce MqttTopicRegistry for mapping IPC message types to MQTT topics
    - Add/expand controlManager functions for temperature and pH control, including IPC messaging and status updates
    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
2025-09-26 Updated MAX31865 library for efficiency and stability. Conversion time for all three sensors optimised from 270ms to 3.8ms
    [main.cpp]
2025-09-27 Fixed conflict on ADC SPI bus due to ISR based SPI reconfiguration in MCP346x lib
    [drv_adc.cpp, drv_adc.h, main.cpp]
2025-09-27 Created Hamilton pH probe driver
2025-10-03 Driver updates, MFC driver added, test code tidy up
2025-10-03 Add MFC setpoint write validation with ±0.01 tolerance
    [main.cpp]
2025-10-03 Added error messages to pH probe on invalid response
2025-10-05 Migrated peripheral drivers to class based libraries to allow multiple or no instances as necessary.
2025-10-05 Added units request from MFC driver
2025-10-10 Completed initial IPC implementation including transfer of sensor data
2025-10-16 Created IO tabs in web UI, inital sensor data to UI
2025-10-16 Config write via IPC for ADC, DAC and RTDs
2025-10-18 Inputs and RTD config and calibration through web UI implemented
2025-10-20 Completed Stepper and DC motor interface to UI
2025-10-21 Added multiple value fields to IPC sensor updates and fixed ADC channel issue with motor control lib
    [ipc_handlers.cpp, ipc_protocol.h, main.cpp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]
2025-10-22 Completed DAC output calibration and UI integration
2025-10-24 Stepper driver bug fix, minor UI enhancements
    [ipc_handlers.cpp]
2025-10-25 Added power sensors to UI
2025-10-26 Stepper motor interface bug fixes, constraints
    [ioConfig.cpp, ipc_handlers.cpp, ipc_protocol.h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]
2025-10-27 Started Device page build, fixed Time and Network issues.
    [ioConfig.cpp, ioConfig.h, network.cpp]
2025-10-27 Re-organised IPC to handle more complex devices, added modbus devices to UI.
2025-10-27 Create notes for Driver implementation
2025-10-28 Completed analogue device integration with web ui
2025-11-01 Completed temperature controller implementation, minify filesystem for faster loading, heater output PWM set bug fix
    [controller_manager.cpp, ctrl_temperature.cpp, drv_output.cpp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]
2025-11-02 Bug fixes to pH controller implementation
    [drv_output.cpp, ioConfig.cpp, network.cpp]
2025-11-02 Bug fixes to pH controller
    [ipc_handlers.cpp, network.cpp]
2025-11-02 feat: bundle custom board definition for ORC-IO-MCU
    - Add Scion ORC M4 board definition to hardware/_ORC board def/
    - Board definition with ATSAME51N20A specs (120MHz, 256KB RAM, 1MB Flash)
    - Custom variant with pin mappings and linker scripts
    - Bootloader binaries (.bin, .uf2) and updater sketch
    - Configure platformio.ini to use bundled board definition
    - Set boards_dir to reference local board definition
    - Set variants_dir for custom pin mappings
    - Fix include typo in sys_init.h (Adafruit_Neopixel -> Adafruit_NeoPixel)
    - Add .gitignore to exclude build artifacts (*.o, *.elf, *.map)
    This enables building and uploading to the custom ORC-IO-MCU board directly
    from the repository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
    [update-bootloader-orc_io_m4-v3.16.0-19-g4365018.ino]
2025-11-03 Serial command bug: The ip command was failing because your serial terminal sends \r\n (carriage return + newline), but the code was only reading until \n, leaving the \r in the string. So it was com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
2025-11-03 Fix delete sensor object on device delete bug
    [network.cpp]
2025-11-05 Completed flow controller (feed and waste controls)
2025-11-10 Added units transform from mL/min to MFC selected units for correct flow set
    [ctrl_do.cpp]
2025-11-15 Added more control to TMC5130 stepper driver
2025-11-16 Stepper enhancements, IPC auto recovery on either mcu restart
2025-11-16 Fixed controller delete handler and improved handler consistency
    [drv_stepper.cpp, network.cpp]
2025-11-21 Improved device fault management
2025-11-22 Added temperature controller disabling on sensor fault
2025-11-22 Added fault propagtion to pH controller to stop running with invalid or broken sensor/mfc objects
    [ctrl_ph.cpp]
